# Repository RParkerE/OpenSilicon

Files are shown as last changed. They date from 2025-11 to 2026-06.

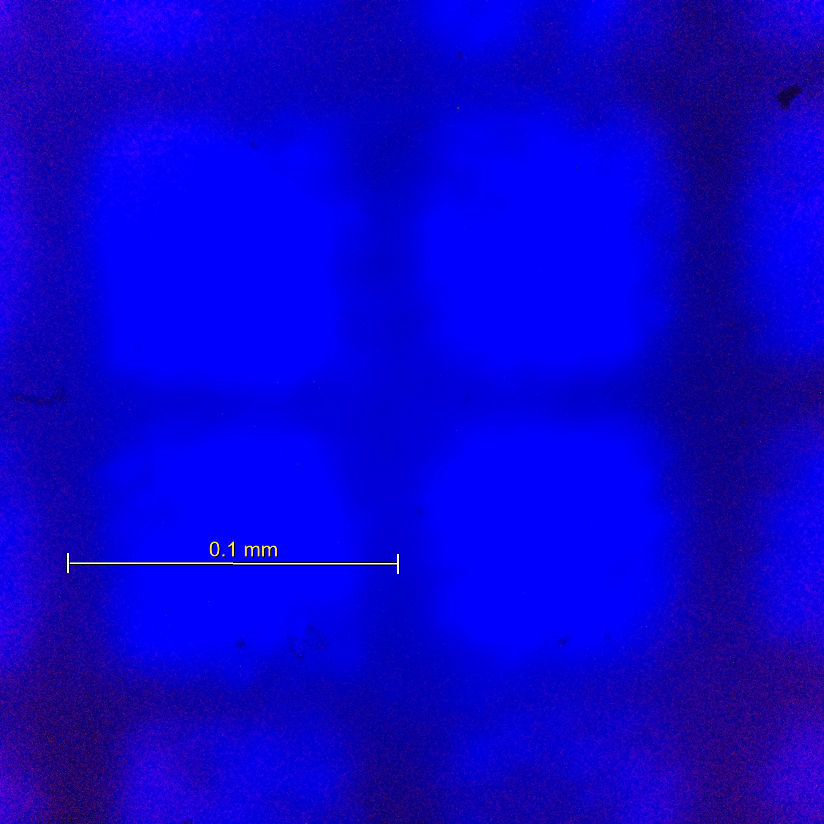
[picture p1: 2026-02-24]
Metrology/FPM/Examples/test_raw_annotated.png

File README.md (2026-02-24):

# OpenSilicon





Open-source semiconductor fabrication for the home lab. Build and operate IC fabrication equipment with detailed guides, CAD files, firmware, and process recipes.

## About

OpenSilicon brings semiconductor fabrication capabilities into the home lab. This project provides comprehensive documentation, designs, and software for building functional IC fabrication equipment for research, education, and experimentation.

We are currently developing the alpha stage of the fabrication pipeline, targeting sub micron feature resolution across the complete process flow: spin coating, direct write lithography, metrology, oxidation, and physical vapor deposition (PVD).

## Status

**Alpha Stage - Active Development**

This is an early-stage project. All equipment designs and processes are works in progress and subject to change. Current development is running two parallel tracks:

**Metrology (FPM / R-FPM)**
- Working prototype complete
- Fourier Ptychographic Microscopy (FPM) and Reflective FPM (R-FPM) under active characterization

**Direct Write Lithography (405nm)**
- Laser control code and firmware complete
- Actively working on motion circuitry and positioning firmware
- Investigating voice coil actuators from blu-ray drive for fine positioning
- Separate 3-axis alignment tool in development

**Other Systems**
- Spin coating system
    - Prototype full assembly complete
    - TODO: Look into web socket connectivity issues
    - TODO: Add a resist fill method
- Oxidation furnace fabrication pipeline
- PVD deposition system integration
- Process characterization and documentation

Join us to help shape the project during these formative stages.

## Getting Started

### Prerequisites

- Basic electronics and mechanical assembly experience
- Interest in semiconductor fabrication and experimental work
- Familiarity with working safely with high temperatures and electrical systems
- 3D printer access (optional, for custom components)

### Next Steps

1. Review the documentation to understand the current state of each component
2. Check open issues to see what's being worked on
3. Start contributing - documentation, testing, and feedback are valuable at this stage

## Equipment in Development

| Equipment | Status | Notes |
|---|---|---|
| Spin Coater | In Progress | Open issues remain |
| FPM / R-FPM Metrology | Working Prototype | Active characterization |
| Direct Write Lithography | In Progress | Laser firmware complete; positioning and alignment in development |
| 3-Axis Alignment Tool | In Progress | Companion to lithography system |
| Oxidation Furnace | In Progress | Initial build phase |
| PVD Deposition System | In Progress | Initial build phase |

## License

OpenSilicon is licensed under the **GNU General Public License v3**. See [LICENSE](LICENSE) for details.

This project integrates components licensed under GPLv3. When using or modifying this project, you must:

- Provide source code to users
- License derivative works under GPLv3
- Include a copy of the license
- State significant changes made

## Contributing

We actively welcome contributions. This project is in its early stages, and input from the community is essential.

### Getting Started with Contributing

1. Check [open issues](../../issues) and [discussions](../../discussions)
2. Reach out with ideas or questions before starting major work
3. Submit pull requests for feedback and discussion

### Ways to Contribute

- Share feedback on design decisions and approaches
- Document your work and help build the knowledge base
- Report issues, problems, observations, and learnings
- Propose design changes or optimizations
- Contribute firmware, software, and design improvements
- Help characterize equipment performance

## Community

- **GitHub Discussions**: [Ask questions and discuss ideas](../../discussions)
- **Issues**: [Report bugs and suggest features](../../issues)
- **Email**: [parker.ellwanger@gmail.com](mailto:parker.ellwanger@gmail.com)

## Roadmap

- [ ] Complete FPM/R-FPM metrology characterization
- [ ] Complete lithography positioning system (voice coil + 3-axis alignment)
- [ ] Complete alpha stage (sub micron) for all equipment
- [ ] Finalize process procedures and characterization data
- [ ] Publish comprehensive build guides
- [ ] Establish baseline performance metrics
- [ ] Improve lithography system resolution to work with the Open PDKs at 130nm process

## Performance & Limitations

OpenSilicon is targeting:

- **Feature resolution**: sub micron (alpha stage)
- **Use case**: Research, education, and experimentation
- **Scale**: Small-batch processing
- **Goal**: Accessible home lab fabrication, not production

## Safety

**This project involves significant hazards.** Home semiconductor fabrication includes:

- High temperature operation (up to 1000°C+)
- High voltage electrical systems
- UV radiation exposure
- Chemical hazards

Users are responsible for understanding and mitigating these risks. Always follow safety procedures and never operate equipment unsupervised.

## Building from Source

All designs are provided in open formats. No proprietary software is required:

- **CAD Files**: STEP and STL formats
- **Firmware**: Open-source microcontroller code
- **Software**: Python and standard development tools

## Acknowledgments

OpenSilicon builds on research and contributions from the open-source hardware community and makers exploring accessible semiconductor fabrication.

## Disclaimer

Use of OpenSilicon designs and instructions is at your own risk. The authors assume no liability for injuries, property damage, or other consequences from assembly, operation, or misuse of equipment built from these designs.

## Support

If you find OpenSilicon interesting, star this repository, share your interests and expertise, contribute to development, and help improve documentation.

**Have questions?** [Start a discussion](../../discussions) or [email us](mailto:parker.ellwanger@gmail.com).

**Found an issue?** [Report it](../../issues/new).

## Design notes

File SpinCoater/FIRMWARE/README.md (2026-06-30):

# OpenSilicon Spin Coater

Open-source firmware for a benchtop **spin coater** built around an ESP32. It
aspirates and dispenses photoresist onto a wafer, sets the dispense height with a
TMC2209-driven Z axis, and spins the wafer at a target RPM with a brushless
motor + ESC to spread the resist into a uniform film.

The machine is configured and operated from a built-in Wi-Fi web UI, with a
local TFT showing live status.

Wiring overview

## Hardware at a glance

| Subsystem | Part | Role |
| --- | --- | --- |
| Controller | ESP32 DevKit (`esp32dev`) | Runs everything |
| Spindle | AM32 ESC + brushless motor | Spins the wafer at target RPM |
| Dispense height (Z)  | TMC2209 + NEMA17 stepper | Raises/lowers the dispense head |
| Resist pump | 28BYJ-48 stepper + ULN2003 driver | Aspirates / dispenses resist |
| Display | ILI9341 320x240 SPI TFT | Local status screen |
| Home reference | Z limit switch | Z homing |

See [docs/HARDWARE.md](docs/HARDWARE.md) for the full bill of materials and the
software toolchain, [docs/WIRING.md](docs/WIRING.md) for the circuit and pin map,
and [docs/ESC_SETUP.md](docs/ESC_SETUP.md) for configuring the ESC.

## Quick start

1. Install [PlatformIO](https://platformio.org/) (the VS Code extension or the
   `pio` CLI).
2. Wire the hardware per [docs/WIRING.md](docs/WIRING.md) and configure the ESC
   per [docs/ESC_SETUP.md](docs/ESC_SETUP.md).
3. Flash the firmware and the web assets:

   ```bash
   pio run -t upload      # firmware
   pio run -t uploadfs    # web UI (data/ -> LittleFS)
   ```

4. Power on. The ESP32 starts a Wi-Fi access point:

   - **SSID:** `OpenSiliconSC`
   - **Password:** `coater123`
   - **URL:** `http://192.168.4.1`

5. Open the URL, build a recipe, **Load to Device**, then **Start**.

## How a recipe runs

Each recipe is an ordered list of steps. For every step the
`ProcessOrchestrator` sequences the hardware:

```
Prime (aspirate) -> lower Z to dispense height -> dispense resist
  -> raise Z to spin height -> ramp spindle to RPM -> hold -> ramp down -> next step
```

Per-step parameters (set in the web UI):

| Field | Meaning |
| --- | --- |
| Prime (mL) | Resist to aspirate before dispensing (0 = skip) |
| Dispense (mL) | Volume dispensed onto the wafer |
| Disp H (mm) | Z height while dispensing (head lowered) |
| Spin H (mm) | Z height while spinning (head retracted) |
| Speed (RPM) | Target spindle speed |
| Ramp (s) | Time to spin up to / down from speed |
| Hold (s) | Time held at speed |

## Architecture

```
WebSocket / TFT
      |
StateMachine  <—events—  ProcessOrchestrator
      |                        |
      |                   Controllers (Spin / Pump / ZAxis)
      |                        |
      +———————————————————> HAL (EscSpinMotor, TMC2209ZAxis, Pump28BYJ48, TFTDisplayHAL)
```

- **HAL** (`include/hal`, `src/hal`) — thin hardware drivers behind interfaces.
- **Controllers** (`include/controllers`, `src/controllers`) — wrap the HAL,
  service motion, and emit completion events.
- **ProcessOrchestrator** (`src/services/ProcessOrchestrator.cpp`) — the recipe
  state machine; the only place that knows the dispense/spin sequence.
- **StateMachine** — owns the machine state (Idle / Running / Paused / Fault).
- **Services** — `TelemetryService` builds a single snapshot; `DisplayService`
  renders it. Neither touches hardware directly.

## Calibration

Two constants in `include/common/configs.h` must be tuned to your mechanics:

- `Z_STEPS_PER_MM` — steps per mm of head travel.
- `PUMP_STEPS_PER_ML` — pump steps per mL (dispense a known volume and adjust).

## Safety

This drives a high-speed brushless motor and dispenses chemicals. Always run the
spindle inside an enclosure, keep the prop balanced, bench-test the ESC with the
motor **unloaded** first, and handle photoresist/solvents with appropriate PPE
and ventilation.

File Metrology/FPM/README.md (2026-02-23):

# R-FPM , Fourier Ptychography Microscope

A sub-500 nm resolution metrology instrument built for lithography feature
verification using Fourier Ptychographic Microscopy (FPM). Every acquisition
runs full FPM reconstruction to achieve synthetic-aperture resolution beyond
the conventional Abbe diffraction limit. The system supports two optical
geometries selected at acquisition time:

| Mode | LED position | Sample type | Phase output |
|---|---|---|---|
| **Reflection** | Above sample via beam splitter | Opaque / reflective (silicon, metal film) | Surface height: `h = φλ/(4π)` |
| **Transmission** | Below sample, shining up | Transparent (glass, quartz, photoresist) | Optical thickness: `h = φλ/(2π(n−1))` |

The reconstruction algorithm (Gerchberg-Saxton iterative phase retrieval)
is identical in both modes. Only the physical LED position and the
phase-to-height interpretation differ.

---

## Table of Contents

1. [Theory and Mathematics](#1-theory-and-mathematics)
2. [Operating Modes](#2-operating-modes)
3. [System Architecture](#3-system-architecture)
4. [Bill of Materials](#4-bill-of-materials)
5. [Hardware Assembly](#5-hardware-assembly)
6. [Software Setup](#6-software-setup)
7. [Configuration Reference](#7-configuration-reference)
8. [Code Module Reference](#8-code-module-reference)
9. [Acquisition Workflow](#9-acquisition-workflow)
10. [Image Quality Assessment](#10-image-quality-assessment)
11. [Reconstruction Algorithm](#11-reconstruction-algorithm)
12. [Calibration Procedure](#12-calibration-procedure)
13. [Target Resolution Budget](#13-target-resolution-budget)

---

## 1. Theory and Mathematics

### 1.1 Fourier Ptychography , Conceptual Foundation

Standard optical microscopy is bounded by the **Abbe diffraction limit**:

```
d = λ / (2 · NA)
```

where `d` is the minimum resolvable feature, `λ` is illumination wavelength,
and `NA` is the objective numerical aperture. For this system at λ = 395 nm
and NA = 0.25:

```
d_conventional = 395 nm / (2 × 0.25) = 790 nm
```

This is insufficient for sub-500 nm lithography verification. FPM overcomes
this limit by synthesizing a **larger effective aperture** from a sequence of
low-resolution images captured under angularly diverse illumination.

Each LED in the 5×5 array illuminates the sample from a different angle,
shifting the object's spatial frequency content into the passband of the
objective. The iterative reconstruction stitches these shifted spectral
patches together in Fourier space, recovering spatial frequencies the
objective cannot capture under on-axis illumination alone.

### 1.2 Illumination Wave Vector

For LED at grid position `(m, n)` where `m, n ∈ {-2, -1, 0, 1, 2}`, the
physical position on the array is:

```
x_led = m · d_pitch      (meters)
y_led = n · d_pitch
```

The illumination angle at the sample plane:

```
θ_x = arctan(x_led / h)
θ_y = arctan(y_led / h)
```

where `h` is the vertical distance from LED array to sample (led_height_mm).
The incident wave vector components:

```
k_x = k₀ · sin(θ_x)
k_y = k₀ · sin(θ_y)
k₀  = 2π / λ            (wave number)
```

The small-angle approximation `sin(θ) ≈ tan(θ)` is valid for `θ < 15°`.
For this system with `d_pitch = 8 mm` and `h = 50 mm`, the corner LED
angle is `arctan(2√2 × 8 / 50) ≈ 24°`, so the full sine is used.

### 1.3 Fourier Space Shift (Pixel Units)

Reconstruction is performed in discrete Fourier space. Each wave
vector is converted to a pixel shift within the upsampled spectrum:

```
Δk_x_pixels = k_x / δk_x
Δk_y_pixels = k_y / δk_y
```

where the Fourier sampling interval is:

```
δk_x = 2π / (W · p_eff)
δk_y = 2π / (H · p_eff)
```

`W`, `H` are the image width and height in pixels, and `p_eff` is the
effective pixel size at the sample plane:

```
p_eff = p_sensor / M
p_sensor = 1.12 μm    (IMX219 native pixel pitch)
M        = 10         (objective magnification)
p_eff    = 0.112 μm = 112 nm
```

### 1.4 Synthetic Numerical Aperture

The synthetic NA after FPM reconstruction is:

```
NA_synthetic = NA_obj + NA_illumination
NA_illumination = sin(θ_max)
θ_max = arctan(√2 · 2 · d_pitch / h)    (corner LED)
```

For this system:

```
θ_max = arctan(√2 × 2 × 0.008 / 0.050) = arctan(0.452) ≈ 24.3°
NA_illumination ≈ sin(24.3°) ≈ 0.412
NA_synthetic    ≈ 0.25 + 0.412 = 0.662
```

Theoretical synthetic resolution:

```
d_synthetic = λ / (2 · NA_synthetic)
            = 395 nm / (2 × 0.662)
            ≈ 298 nm
```

This is well within the sub-500 nm target.

> **Requirement for this to hold:** Adjacent LED spectra must overlap in
> Fourier space by at least 30%. Overlap fraction is:
>
> ```
> overlap = 1 - (|Δk| / (2 · k_obj_radius))
> k_obj_radius = k₀ · NA_obj
> ```
>
> If `|Δk| > 2 · k_obj_radius`, spectra do not overlap and the
> Gerchberg-Saxton update is operating blind (no spectral continuity
> constraint). The primary failure mode to check during calibration.

### 1.5 Gerchberg-Saxton Phase Retrieval

The reconstruction is based on the
Gerchberg-Saxton (GS) algorithm adapted for FPM by Zheng et al. (2013).

**State:** A complex-valued high-resolution object spectrum
`O(k_x, k_y)` of shape `(N·U, M·U)` where `U` is the upsample factor
(default 4×).

**Per-iteration update for each LED `i`:**

1. Extract the spectral patch centered at `(Δk_xi, Δk_yi)`:
   ```
   ψ_i(k) = O(k + Δk_i) · P(k)
   ```
   where `P(k)` is the binary pupil function (objective aperture).

2. Inverse FFT to spatial domain:
   ```
   φ_i(r) = ℱ⁻¹{ψ_i(k)}
   ```

3. **Amplitude constraint** , replace amplitude with square root of
   measured intensity, preserve phase:
   ```
   φ_i'(r) = √I_i(r) · exp(j · arg(φ_i(r)))
   ```

4. Forward FFT back to Fourier domain:
   ```
   ψ_i'(k) = ℱ{φ_i'(r)}
   ```

5. Update high-resolution spectrum:
   ```
   O'(k + Δk_i) = O(k + Δk_i) · (1 - P(k)) + ψ_i'(k) · P(k)
   ```

**Convergence metric** (relative change between iterations):

```
ε = ‖O_new - O_old‖_F / ‖O_old‖_F
```

Iteration stops when `ε < convergence_threshold` (default 1×10⁻⁴) or
`max_iterations` is reached (default 15).

**Final reconstruction:**

```
object(r) = ℱ⁻¹{O(k)}
amplitude  = |object(r)|
phase      = arg(object(r))
```

### 1.6 Pupil Function

The objective lens is modeled as a binary circular aperture:

```
P(k) = 1   if √(k_x² + k_y²) ≤ NA_obj / λ
P(k) = 0   otherwise
```

The coherent transfer function (CTF) of a diffraction-limited
objective in the paraxial approximation (Born & Wolf, §10.6).

### 1.7 Phase-to-Height Conversion (Mode-Dependent)

The phase output of the GS reconstruction, `φ(r) ∈ [−π, π]`, encodes a
physical quantity that depends on the optical geometry.

**Reflection mode** (light travels to the surface and back , double pass):

```
φ = (4π / λ) · h
→  h = φλ / (4π)
```

`h` is the surface height in nm. Sensitivity is `λ/2 = 197 nm` per `2π`
of phase, so one full phase wrap corresponds to ~197 nm of topography.

**Transmission mode** (light passes through the sample once , single pass):

```
φ = (2π / λ) · (n − 1) · t
→  t = φλ / (2π(n − 1))
```

`t` is the physical thickness of the sample in nm. `n` is the sample
refractive index (configured via `sample_refractive_index` in `config.py`).
Sensitivity is `λ / (n − 1)` per `2π` of phase , for glass (`n ≈ 1.5`),
one full phase wrap corresponds to ~790 nm of thickness.

**Refractive index reference values:**

| Material | n at 395 nm |
|---|---|
| Borosilicate glass | 1.47 |
| Fused silica (quartz) | 1.47 |
| Positive photoresist (AZ) | 1.64 |
| PMMA | 1.50 |
| Water | 1.34 |
| Air (reference) | 1.00 |

The `visualize.py` dashboard applies the correct formula automatically by
reading the mode from `status.json`. The refractive index can be overridden
interactively in the 3D surface tab without re-running reconstruction.

### 1.8 Abbe Resolution Limit Reference Table

| Configuration | NA | Resolution |
|---|---|---|
| Conventional (this objective) | 0.25 | 790 nm |
| FPM synthetic (estimated) | 0.662 | 298 nm |
| Target | , | < 500 nm |
| IMX219 Nyquist at sample plane | , | 224 nm |

The sensor Nyquist limit at the sample plane (`2 × p_eff = 224 nm`) is the
hard floor below which no reconstruction can recover detail regardless of NA.
The synthetic resolution (298 nm) is above this floor, so the sensor is not
the bottleneck.

---

## 2. Operating Modes

Both modes run full FPM reconstruction. The mode controls only where the
LED array is physically mounted and how the phase output is interpreted.

### 2.1 Reflection Mode

```
         [ 5×5 UV LED array ]
                  │  angled illumination
                  ▼
         [ 50/50 Beam Splitter ]  ← mounted at 45°
                  │  reflected arm
                  ▼
            [ Sample plane ]       ← opaque / reflective
                  │  backscattered light
                  ▼
          [ 10× Objective ]
                  │
                  ▼
           [ IMX219 Camera ]
```

**Use for:** Silicon wafers, metal thin films, hard disk platters, any
surface that scatters or reflects light without being transmissive.

**Phase output:** Surface topography. Each pixel's phase value encodes how
much higher or lower that point is relative to the mean surface plane.

**Beam splitter requirement:** The 46×57×0.5 mm 50/50 plate is in the
optical path. It introduces a 50% transmission loss on both the
illumination and collection passes (25% total efficiency). The
primary reason exposure times are long in reflection mode.

### 2.2 Transmission Mode

```
            [ Sample plane ]       ← transparent (glass, resist, quartz)
                  │  transmitted light
                  ▼
          [ 10× Objective ]
                  │
                  ▼
           [ IMX219 Camera ]

         [ 5×5 UV LED array ]     ← mounted BELOW sample, shining up
```

**Use for:** Thin film samples on transparent substrates, patterned
photoresist on glass, biological specimens on glass slides, any sample
that transmits UV light.

**Phase output:** Optical path length through the sample. Combined with
the refractive index, this gives physical thickness at each pixel.

**Beam splitter requirement:** Not needed. Remove it from the optical path
or fold it out of the beam. Transmission efficiency is significantly
higher , exposures can be 5–10× shorter than reflection mode for the
same SNR.

**LED array repositioning:** The LED jig must be moved from above the
beam splitter to below the sample stage. The `led_height_mm` parameter
in `config.py` must be updated to the new measured distance from the
LED array plane to the sample underside.

### 2.3 What Does Not Change Between Modes

- The GS reconstruction algorithm (`reconstruction.py`) , identical.
- The k-space coordinate calculation (`utils.py`) , identical. Illumination
  angle geometry is the same whether the LED is above or below.
- The `val.py` quality assessment , identical. Alignment, exposure, and
  focus checks apply equally in both modes.
- The session file format , identical. `led_NN.png`, `status.json`, and
  the TIFF outputs have the same structure.

### 2.4 Selecting a Mode

```bash
# Reflection mode (default) , opaque sample, beam splitter in path
python client.py --mode reflection

# Transmission mode , transparent sample, LED below stage
python client.py --mode transmission

# Set default in .env to avoid passing --mode every time
echo "FPM_MODE=transmission" >> .env
```

The mode is stored in the session manifest at capture time and in
`status.json` at reconstruction time. The `visualize.py` dashboard reads
it automatically , no manual configuration is needed when browsing results.

---

## 3. System Architecture

```
┌─────────────────────────────────────────────────────────────┐
│                    Raspberry Pi 4B                           │
│                                                             │
│   client.py ─── picamera2 ─── IMX219 sensor                │
│       │                            │                        │
│       │ pyserial (115200 baud)     │ CSI-2 lane             │
│       │                            ▼                        │
│       │                       led_XX.png                    │
│       │                            │                        │
│       │                      HTTP POST /upload              │
│       │                            │                        │
└───────┼────────────────────────────┼────────────────────────┘
        │                            │
        ▼                            ▼
┌──────────────┐           ┌─────────────────────────────────┐
│   ESP32      │           │     Server (Docker / bare)      │
│              │           │                                 │
│ SPI → 4×    │           │   server.py (FastAPI)           │
│ 74HC595     │           │   reconstruction.py (GS)        │
│ shift regs  │           │   utils.py (k-space coords)     │
│             │           │   visualize.py (Streamlit)      │
│ 25 UV LEDs  │           │   val.py (QA tool, local)       │
│ 5×5 grid    │           │                                 │
└──────────────┘           │   :8000 REST API               │
                           │   :8501 Dashboard              │
                           └─────────────────────────────────┘
```

**Optical path , Reflection mode** (LED above sample, beam splitter required):

```
  UV LED array (395 nm)
        │  angled illumination
        ▼
  ┌─────────────┐
  │ Beam Splitter│  46×57×0.5mm, 50/50 ratio
  └─────┬───────┘
        │ reflected down onto sample
        ▼
    Sample plane  (opaque/reflective)
        │ backscattered light up through splitter
        ▼
  10× Objective (NA 0.25)
        │
        ▼
  IMX219 Camera
```

**Optical path , Transmission mode** (LED below sample, no beam splitter):

```
  IMX219 Camera
        │
        ▼
  10× Objective (NA 0.25)
        │
        ▼
    Sample plane  (transparent)
        │ transmitted light
        ▼
  UV LED array (395 nm)  ← mounted below stage
```

### 3.1 Data Flow Per Acquisition

```
python client.py --mode <reflection|transmission>
    → ESP32 serial "L{n} E{ms}"
    → LED n fires for exposure_ms
    → Pi camera captures frame
    → saved as led_NN.png
    → repeated for all 25 LEDs
    → mode written to session manifest JSON
    → 25 images uploaded to server
    → POST /process/{session_id}?mode=<reflection|transmission>
    → mode stored in status.json
    → reconstruction runs (identical algorithm in both modes)
    → amplitude + phase TIFFs written to session dir
    → Streamlit dashboard reads mode from status.json
    → applies correct phase-to-height formula for the mode
```

---

## 4. Bill of Materials

| # | Component | Part / Spec | Role |
|---|---|---|---|
| 1 | **Objective Lens** | OMAX 10× Achromatic, NA 0.25, RMS thread, 160mm tube length | Primary imaging element. Sets base resolution and field of view. |
| 2 | **Microcontroller** | ESP32 (38-pin DevKit, dual-core 240 MHz, Wi-Fi/BT) | LED array sequencing via SPI + 4× shift registers. Serial command interface to Pi. |
| 3 | **UV LED Array** | EDGELEC 3mm, 395–400 nm, flat lens, DC 3V, ~20 mA/LED. 25 pcs arranged in 5×5 grid on 8 mm pitch PCB/jig | Angularly diverse illumination source. UV chosen for shortest λ → best diffraction limit. |
| 4 | **Camera** | Arducam IMX219 8MP, RPi NoIR (no IR filter), CSI-2 | Scientific imaging sensor. 3280×2464 native, 1.12 μm pixel pitch. NoIR variant avoids IR-cut filter UV absorption. |
| 5 | **Beam Splitter** | Optical glass, 46×57×0.5mm, 50/50 split ratio | Directs LED illumination onto sample in reflection geometry while passing return light to camera. |
| 6 | **Shift Registers** | SN74HC595N, 8-bit, DIP-16, 3-state output. 4 pcs in daisy-chain (32 outputs, 25 used) | Expands ESP32 SPI to 25 individual LED control lines. |
| 7 | **SBC** | Raspberry Pi 4B (4GB RAM recommended) | Acquisition host: runs client.py, picamera2, serial comms. |

### 4.1 Supplementary Materials

| Item | Specification | Notes |
|---|---|---|
| LED current-limiting resistors | 100 Ω for 6–12V supply; included in EDGELEC kit | Verify drop across LED (~3.2V forward) at 20 mA |
| Sample slide | Quartz preferred; plastic usable with <8s exposure | See §12 fluorescence note |
| Tube adapter | RMS-to-C-mount or RMS-to-M12 for IMX219 board | Mechanical coupling between objective and sensor |
| Optical rail / cage system | 30mm or 60mm cage, Thorlabs or equivalent | Rigidity critical , any vibration aliases phase error |
| LED jig/PCB | 5×5 matrix, 8mm pitch, 3mm LED holes | Custom or perf-board construction |
| DC power supply | 5V/3A for Pi; 9V/1A for LED array; 3.3V/5V for ESP32 | Separate supplies reduce ground noise |

---

## 5. Hardware Assembly

### 5.1 LED Array Wiring (ESP32 → 74HC595 Chain)

The four shift registers are daisy-chained: `Q7'` (serial out) of register N
connects to `DS` (serial in) of register N+1.

```
ESP32 GPIO 23 (MOSI) ──► DS   [SR1] Q7' ──► DS   [SR2] Q7' ──► DS   [SR3] Q7' ──► DS   [SR4]
ESP32 GPIO 18 (SCK)  ──► SHCP (all four, parallel)
ESP32 GPIO 5  (LATCH)──► STCP (all four, parallel)
GND ─────────────────────────────────────────────────────────────────────────────────── GND
```

`SPI.transfer32()` clocks 32 bits MSB-first. Bit 0 activates the output on
the last register in the chain (SR4 pin Q0). Bit 24 activates SR1 pin Q0.
Bits 25–31 are unused.

**LED index mapping** (1-based, matches `led_NN.png` filenames):

```
LED grid (physical, viewed from above):
Row 0 (top):   LED 1  LED 2  LED 3  LED 4  LED 5
Row 1:         LED 6  LED 7  LED 8  LED 9  LED 10
Row 2 (center):LED 11 LED 12 LED 13 LED 14 LED 15
Row 3:         LED 16 LED 17 LED 18 LED 19 LED 20
Row 4 (bottom):LED 21 LED 22 LED 23 LED 24 LED 25

Shift register bit assignment:
LED index n → bit (n-1) in the 32-bit SPI word
```

> **Critical:** Verify your physical wiring matches this mapping before
> the first acquisition. Fire LEDs 1, 5, 21, 25 (corners) and 13 (center)
> individually and confirm the centroid positions are as expected.
> See §11 Calibration Procedure.

### 5.2 Serial Command Protocol (ESP32)

Communication is ASCII over UART at 115200 baud, newline-terminated.

| Command | Response | Description |
|---|---|---|
| `L{n} E{ms}\n` | `PULSING_LED_INDEX:{n}` then `PULSE_COMPLETE` | Fire LED n (1-25) for ms milliseconds |
| `STATUS\n` | `LED_ACTIVE:{n}` or `LED_ACTIVE:0` | Query active LED |
| `RESET\n` | `SYSTEM_RESET` | Clear all registers, safe state |

Maximum pulse duration: 180,000 ms (3 minutes). The ESP32 auto-shutoff
timer fires `PULSE_COMPLETE` and extinguishes the LED when elapsed.

### 5.3 Optical Alignment

1. Mount beam splitter at 45° to both the illumination axis and the imaging axis.
2. Center the objective below the beam splitter exit port.
3. Place sample on the objective focal plane (~17.4 mm WD for this objective).
4. Align the LED array so LED 13 (center) illumination hotspot falls at the
   image center `(1024, 1024)` for a 2048×2048 capture.
5. The LED array plane should be parallel to the sample plane. Use a spirit
   level on the LED jig.
6. Target `led_height_mm = 50` ± 2 mm. Measure with calipers and update `config.py`.

---

## 6. Software Setup

### 6.1 Prerequisites

- Python 3.10+
- [`uv`](https://github.com/astral-sh/uv) package manager
- Docker + Docker Compose (for server deployment)
- Arduino IDE or `arduino-cli` (for ESP32 firmware)

### 6.2 Python Environment (Client + QA Tools)

```bash
# Clone the repository
git clone https://github.com/<your-org>/r-fpm.git
cd r-fpm

# Create virtual environment and install dependencies
uv venv
uv pip install -r requirements.txt

# Activate environment
source .venv/bin/activate        # Linux / macOS
.venv\Scripts\activate           # Windows
```

### 6.3 Server Deployment (Docker)

```bash
# Build and start the API server and Streamlit dashboard
docker compose up -d

# Verify health
curl http://localhost:8000/health

# View logs
docker compose logs -f api
```

The server exposes:
- `http://localhost:8000` , FastAPI REST API
- `http://localhost:8501` , Streamlit visualization dashboard

### 6.4 Environment Variables

Override any config value with the `FPM_` prefix:

```bash
# Example: switch to quartz target profile
export FPM_ACQUISITION__BF_EXPOSURE_US=60000000
export FPM_ACQUISITION__ANALOG_GAIN=8.0
export FPM_OPTICAL__LED_HEIGHT_MM=52.5   # measured value
```

### 6.5 ESP32 Firmware

Open `firmware/led_controller.ino` in Arduino IDE. Set board to
**ESP32 Dev Module**. Flash via USB. Verify with serial monitor at 115200 baud ,
`SHIFT_REGISTER_SYSTEM_READY` should print on boot.

---

## 7. Configuration Reference

All system parameters are defined in `config.py` using Pydantic settings.
Values can be overridden via environment variables or `.env` file.

### 7.1 SystemConfig (top-level)

| Parameter | Default | Description |
|---|---|---|
| `mode` | `"reflection"` | Operating geometry. `"reflection"` = LED above sample via beam splitter; `"transmission"` = LED below sample. Override with `FPM_MODE=transmission`. |

### 7.2 OpticalConfig

| Parameter | Default | Unit | Description |
|---|---|---|---|
| `wavelength_nm` | 395.0 | nm | LED center wavelength |
| `na_objective` | 0.25 | , | Objective numerical aperture |
| `pixel_size_um` | 1.12 | μm | IMX219 native pixel pitch |
| `magnification` | 10.0 | × | Objective magnification |
| `led_pitch_mm` | 8.0 | mm | LED-to-LED spacing in array |
| `led_height_mm` | 50.0 | mm | Distance from LED array to sample plane. **Remeasure and update when switching to transmission mode** , the LED array moves from above the beam splitter to below the sample stage. |
| `sample_refractive_index` | 1.5 | , | Sample refractive index for transmission mode thickness conversion. Has no effect in reflection mode. Typical values: glass/quartz 1.47, photoresist 1.64, water 1.34. |

**Derived properties** (read-only, computed at runtime):

| Property | Formula | Typical value |
|---|---|---|
| `pixel_size_m` | `pixel_size_um × 1e-6 / magnification` | 112 nm |
| `theoretical_resolution_nm` | `wavelength_nm / (2 × na_objective)` | 790 nm |
| `synthetic_na_estimate` | `na_obj + sin(arctan(√2 × 2 × pitch / height))` | 0.662 |
| `synthetic_resolution_nm` | `wavelength_nm / (2 × synthetic_na_estimate)` | ~298 nm |

### 7.3 AcquisitionConfig

| Parameter | Default | Description |
|---|---|---|
| `serial_port` | `/dev/ttyUSB0` | ESP32 serial device |
| `camera_width` | 2048 | Capture width (pixels) |
| `camera_height` | 2048 | Capture height (pixels) |
| `bf_exposure_us` | 9,600,000 | Bright-field exposure (9.6 s) |
| `df_exposure_us` | 9,600,000 | Dark-field exposure (9.6 s) |
| `analog_gain` | 16.0 | Camera gain (1.0–16.0) |
| `capture_timeout_s` | 60 | Max wait per frame |

### 7.4 Exposure Profiles

| Profile | Target | bf_exposure_us | df_exposure_us | analog_gain | Signal |
|---|---|---|---|---|---|
| Plastic target (current) | Below fluorescence threshold | 7,000,000 | 7,000,000 | 16.0 | 5–10% FS , marginal |
| **Quartz target (recommended)** | Maximum SNR | 60,000,000 | 120,000,000 | 8.0 | 30–60% FS , good |
| Blue LED 470 nm (best) | Fast + no fluorescence | 1,000,000 | 3,000,000 | 4.0 | 40–80% FS , excellent |

> **Fluorescence warning:** The plastic calibration slide exhibits
> UV-induced fluorescence (visible as a red/pink channel bleed in the
> camera raw) at exposures exceeding ~8–10 seconds. This contaminates
> the measured intensity with incoherent emission rather than coherent
> scattered signal, violating the FPM measurement model. Use a quartz
> slide for exposures above 8 s.

### 7.5 ReconstructionConfig

| Parameter | Default | Range | Description |
|---|---|---|---|
| `upsample_factor` | 4 | 2–8 | High-res grid size = input × upsample_factor |
| `max_iterations` | 15 | 1–100 | GS iteration limit |
| `convergence_threshold` | 1×10⁻⁴ | >0 | Early stopping relative change |
| `regularization_weight` | 0.01 | 0–1 | Tikhonov noise suppression |

---

## 8. Code Module Reference

### 8.1 `config.py` , System Configuration

Centralized Pydantic settings model. All physical constants live here.

**`OperatingMode`** is a `Literal["transmission", "reflection"]` type alias
exported at module level. All other modules import this type to ensure
consistent validation:

```python
from config import config, OperatingMode
```

**`SystemConfig.mode`** sets the system-wide default geometry. Override
at the environment level without touching code:

```bash
FPM_MODE=transmission python client.py
# or persistently:
echo "FPM_MODE=transmission" >> .env
```

**`OpticalConfig.sample_refractive_index`** (default 1.5) is consumed
only by `visualize.py` in transmission mode when converting phase to
physical thickness. It has no effect on the reconstruction algorithm.

```python
from config import config

print(config.mode)                              # 'reflection'
print(config.optical.synthetic_resolution_nm)  # ~298 nm
print(config.optical.sample_refractive_index)  # 1.5
config.print_summary()                         # prints mode-aware summary
```

### 8.2 `utils.py` , Mathematical Utilities

**`get_k_coordinates(led_pitch_m, led_height_m, wavelength_m, na_obj, pixel_size_m, img_shape)`**

Computes the Fourier-space pixel shifts for all 25 LED positions.
Returns `(kx_shifts, ky_shifts)` as flat arrays of length 25.
These are the `Δk` values used in the GS update step.

**`generate_pupil(img_shape, na_obj, wavelength_m, pixel_size_m)`**

Returns a binary complex64 array representing the objective aperture
in Fourier space. Pixel value 1.0 inside NA cutoff, 0.0 outside.

**`calculate_theoretical_resolution(wavelength_m, na_effective)`**

Returns Abbe limit `λ / (2 × NA)` in meters.

**`estimate_synthetic_na(na_obj, led_pitch_m, led_height_m, wavelength_m)`**

Returns estimated synthetic NA based on LED geometry. Includes overlap
check: if adjacent spectra do not overlap, logs a warning.

### 8.3 `reconstruction.py` , FPM Reconstruction Engine

```python
from config import config
from reconstruction import FPMReconstructor

reconstructor = FPMReconstructor(config)
amplitude, phase, metadata = reconstructor.reconstruct(images, kx_shifts, ky_shifts)
```

**`FPMReconstructor.reconstruct(images, kx_shifts, ky_shifts)`**

- `images`: List of 25 float32 grayscale arrays
- `kx_shifts`, `ky_shifts`: Arrays from `get_k_coordinates()`
- Returns: amplitude array, phase array (radians), metadata dict

The metadata dict contains convergence history, processing time, and
the final relative change value. Useful for diagnosing reconstruction
quality without inspecting the output image.

### 8.4 `server.py` , FastAPI REST Server

| Endpoint | Method | Description |
|---|---|---|
| `/health` | GET | System health, default mode, and optical parameters |
| `/sessions` | GET | List all acquisition sessions |
| `/sessions/{id}/status` | GET | Reconstruction progress and mode |
| `/upload/{id}` | POST | Upload image stack (multipart) |
| `/process/{id}?mode=reflection` | POST | Trigger reconstruction with specified mode |

**`POST /process/{session_id}?mode=<mode>`** accepts `mode` as a query
parameter. The mode defaults to `config.mode` if omitted. It is stored in
`status.json` immediately (even before reconstruction completes) so the
visualizer can display the correct formula while processing is in progress.

**`GET /sessions/{id}/status`** response now includes a `"mode"` field:

```json
{
  "session_id": "fpm_1771347801",
  "status": "complete",
  "mode": "transmission",
  "frames_uploaded": 25,
  "reconstruction_complete": true
}
```

### 8.5 `client.py` , Raspberry Pi Acquisition Client

Runs on the Raspberry Pi. Sequences through all 25 LEDs, captures one
image per LED, and uploads the stack to the server.

**`--mode` flag** is the primary user-facing control for selecting the
optical geometry. It defaults to `config.mode` (set in `.env`):

```bash
python client.py --mode reflection   # LED above, beam splitter in path
python client.py --mode transmission # LED below, beam splitter removed
```

The mode is propagated through the full pipeline:
- Written into `{session_id}_manifest.json` at capture time (per-frame)
- Sent as `?mode=` query parameter to `POST /process/{session_id}`
- The server stores it in `status.json` for the visualizer to read

**`FPMConductor`** now takes `mode: OperatingMode` as a constructor
argument. The BF/DF LED split logic is identical in both modes , inner
3×3 LEDs always use `bf_exposure_us`, outer 16 use `df_exposure_us`.

### 8.6 `visualize.py` , Streamlit Dashboard

Runs at `:8501`. Reads the operating mode from `status.json` (written by
server) or the session manifest (written by client) and applies the
correct phase-to-height formula automatically.

**`load_session_mode(session_path)`** reads mode with a three-level fallback:
1. `status.json` → `"mode"` field (primary , written at reconstruction time)
2. `{session_id}_manifest.json` → `"mode"` field (written at capture time)
3. `config.mode` (fallback for sessions captured before mode tracking)

**`phase_to_height(phase_map, wavelength_nm, mode, refractive_index)`**
applies the correct conversion formula:

```python
# Reflection , double-pass surface height
height_nm = (phase_rad * wavelength_nm) / (4 * pi)

# Transmission , single-pass optical thickness
height_nm = (phase_rad * wavelength_nm) / (2 * pi * (n - 1))
```

In transmission mode the dashboard exposes a live `n` override slider in
the 3D surface tab, allowing immediate rescaling of the height axis for
different sample materials without re-running reconstruction.

**Mode badge** is displayed in both the sidebar and the main area so the
geometry is unambiguous when switching between sessions of different modes.

Provides:
- Session browser (sorted by modification time)
- 16-bit amplitude and phase image display
- Interactive 3D surface plot (Plotly) with quality slider
- RMS roughness, mean height, and peak-to-valley metrics

### 8.7 `val.py` , Image Quality Assessment Tool

Standalone diagnostic tool. Runs locally on the acquisition machine or
server. Evaluates each of the 25 LED images across three independent axes:

| Axis | Method | Metric | PASS threshold |
|---|---|---|---|
| **Alignment** | Intensity-weighted centroid of top-5% pixels | Distance from image center (px) | < 100 px |
| **Exposure** | Mean intensity + clipping fraction | % of full scale | 8–80% |
| **Focus** | Laplacian variance of central 50% ROI | Lap. var (unitless) | > 15.0 |

```bash
# Run quality assessment on a session
python val.py data/fpm_1771347801

# Save PNG report to custom path
python val.py fpm_1771347801 --output ./reports/session_qa.png
```

**Output files per session:**
- `alignment_analysis.png` , 3×2 quality dashboard
- `alignment_results.json` , Full per-LED metrics + thresholds

#### Focus Threshold Calibration

The `FOCUS_PASS = 15.0` threshold is a starting point. Calibrate it
for your specific sample and objective:

1. Capture a single image with the system in known-good focus.
2. Run `val.py` and note the `laplacian_variance` for that LED.
3. Set `FOCUS_PASS` to ~80% of that value in `val.py`.

For a blank slide (no sample), the Laplacian variance will be near zero
regardless of focus , this is expected. The focus metric only works when
the sample has spatial features at or near the sensor resolution limit.

---

## 9. Acquisition Workflow

Every acquisition runs full FPM reconstruction. The only choice is the
optical geometry , reflection or transmission , which determines where
the LED array sits and what the phase output means.

### 9.1 Reflection Mode Acquisition

LED array above sample via beam splitter. Use for opaque/reflective samples.

```bash
# 1. Ensure beam splitter is in the optical path.
#    LED array should be above the beam splitter at led_height_mm from sample.

# 2. Start server (if not already running)
docker compose up -d

# 3. On Raspberry Pi: run full 25-LED acquisition
python client.py --mode reflection --session fpm_$(date +%s)

# 4. Monitor reconstruction status
curl http://<server_ip>:8000/sessions/<session_id>/status

# 5. View results in dashboard (mode badge shown automatically)
open http://<server_ip>:8501
```

### 9.2 Transmission Mode Acquisition

LED array below sample, shining up through specimen. Use for transparent
samples. Before running:

1. **Remove or fold the beam splitter** out of the optical path between
   the objective and camera.
2. **Reposition the LED array** below the sample stage, shining upward.
3. **Measure the new `led_height_mm`** (LED array plane to sample underside)
   with calipers and update `config.py` or set `FPM_OPTICAL__LED_HEIGHT_MM`.

```bash
# Set new height if different from 50 mm
export FPM_OPTICAL__LED_HEIGHT_MM=42.5

# Run acquisition
python client.py --mode transmission --session fpm_$(date +%s)

# View results , dashboard applies transmission formula automatically
open http://<server_ip>:8501
```

### 9.3 Setting a Default Mode

To avoid passing `--mode` on every run, set it in `.env`:

```bash
echo "FPM_MODE=transmission" >> .env
# Now client.py, server.py, and visualize.py all default to transmission
```

### 9.4 LED Firing Order

LEDs fire in index order 1→25 (row-major, top-left to bottom-right).
The angular diversity and k-space shift mapping are identical in both
reflection and transmission modes.

BF LEDs (inner 3×3, indices 7, 8, 9, 12, 13, 14, 17, 18, 19): use
`bf_exposure_us`. DF LEDs (outer 16): use `df_exposure_us`.

---

## 10. Image Quality Assessment

Before triggering reconstruction, run `val.py` to verify the stack is
usable. The tool will flag any LED whose image fails on alignment, exposure,
or focus, and will print a per-LED table and an overall readiness verdict.

### 10.1 Interpreting the Table

```
LED   OVERALL   ALIGN   DIST    EXPOSE   MEAN%   CLIP%   FOCUS   LAP_VAR
1     PASS      PASS    45.2px  PASS     31.4%   0.00%   PASS     24.55
2     WARN      WARN    187.0px PASS     28.1%   0.00%   PASS     19.22
  -> ALIGN WARN: centroid 187px from center (PASS < 100px).
3     FAIL      PASS    62.0px  FAIL     3.1%    0.00%   PASS     21.33
  -> EXPOSURE FAIL: mean 3.1% , severely underexposed. Increase exposure.
```

### 10.2 Status Color Key

| Status | Meaning |
|---|---|
| **PASS** | Axis is within specification |
| **WARN** | Axis is marginal , reconstruction may succeed but quality is reduced |
| **FAIL** | Axis is out of specification , reconstruction likely to fail or produce artifacts |

### 9.3 Acquisition Readiness Verdict

| Verdict | Condition |
|---|---|
| `READY` | Zero FAILs, ≤5 WARNs |
| `MARGINAL` | 1–3 FAILs , address before acquiring |
| `NOT READY` | >3 FAILs , do not reconstruct |

---

## 11. Reconstruction Algorithm

### 11.1 High-Resolution Grid Initialization

The high-resolution spectrum is initialized using the center LED (index 12,
0-based) image. This provides the initial estimate of the object spectrum in
the passband of the objective. All other spectral regions start at zero.

```
high_res_shape = (2048 × upsample_factor, 2048 × upsample_factor)
               = (8192, 8192) at 4× upsample
```

### 11.2 Iteration Sequence

```
for iteration in range(max_iterations):
    for each LED (25 total):
        extract patch → apply pupil → iFFT → replace amplitude → FFT → update spectrum
    compute ε (relative change)
    if ε < convergence_threshold: break
```

Each full pass through all 25 LEDs constitutes one iteration. Typical
convergence at 15 iterations with 9.6 s exposures (marginal SNR).
With quartz target at 60 s exposure, convergence is typical at 5–8 iterations.

### 11.3 Output Files

| File | Format | Content |
|---|---|---|
| `reconstruction_amplitude.tiff` | 16-bit grayscale TIFF | Normalized amplitude (0–65535) |
| `reconstruction_phase.tiff` | 16-bit grayscale TIFF | Phase mapped from \[-π, π\] → \[0, 65535\] |
| `status.json` | JSON | Session status, operating mode, frame count, convergence metrics |

**Phase-to-height conversion** in `visualize.py` , formula selected by mode:

```python
phase_radians = (phase_uint16 / 65535.0) * (2π) - π

# Reflection mode (double-pass surface topography)
height_nm = (phase_radians × wavelength_nm) / (4π)

# Transmission mode (single-pass optical thickness)
height_nm = (phase_radians × wavelength_nm) / (2π × (n - 1))
```

The mode is read from `status.json` automatically. No manual formula
selection is required when viewing results in the dashboard.

---

## 12. Calibration Procedure

### 12.1 LED Mapping Verification

Fire each LED individually via the ESP32 serial console and measure
the centroid shift. Compare against geometric prediction:

```bash
# On any machine with the session data
python val.py data/<session_id>
```

Expected centroid positions (approximate, at 50mm height, 8mm pitch):

| LED | Grid pos | Expected centroid (approx) |
|-----|---|---|
| 13 (center) | (0, 0) | ~(1024, 1024) |
| 1 (TL corner) | (-2, -2) | ~(840, 840) |
| 5 (TR corner) | (+2, -2) | ~(1208, 840) |
| 21 (BL corner) | (-2, +2) | ~(840, 1208) |
| 25 (BR corner) | (+2, +2) | ~(1208, 1208) |

If centroids do not match, check:
1. `led_height_mm` , measure physically and update `config.py`
2. `led_pitch_mm` , measure center-to-center with calipers
3. Shift register wiring , confirm LED index to physical position mapping

### 12.2 Focus Calibration

1. Place a calibration target (USAF 1951 chart or lithography sample) on the stage.
2. Manually adjust focus by translating the objective or stage in Z.
3. Run `val.py` after each Z adjustment.
4. The `LAP_VAR` column increases monotonically as you approach focus.
5. Lock the focus at maximum `LAP_VAR` for the center LED (LED 13).
6. Record that value as your `FOCUS_PASS` baseline in `val.py`.

### 12.3 Exposure Calibration

Target 20–60% of full scale (51–153 DN out of 255) in the mean intensity
column of `val.py`. Adjust `bf_exposure_us` and `df_exposure_us` in
`config.py` until bright-field and dark-field LEDs both land in this range.

For the current plastic target with UV LEDs:
- Bright-field (center LEDs): target ~50–100 DN mean
- Dark-field (outer LEDs): target ~30–80 DN mean (less efficient coupling)
- **Hard limit at 7,000,000 μs (7 s) to avoid fluorescence**

For quartz target: no fluorescence limit applies. Target 80–150 DN mean
at 60–120 s exposure.

---

## 13. Target Resolution Budget

| Budget item | Value | Notes |
|---|---|---|
| Illumination wavelength | 395 nm | UV LED center |
| Objective NA | 0.25 | OMAX 10× achromat |
| Conventional resolution | 790 nm | Abbe limit at objective NA |
| LED illumination NA | 0.412 | Corner LED at 50mm height |
| Synthetic NA (estimated) | 0.662 | Sum: obj + illumination |
| Synthetic resolution (estimated) | **298 nm** | Abbe at synthetic NA |
| Sensor Nyquist at sample | 224 nm | 2 × 112 nm effective pixel |
| **Target** | **< 500 nm** | Lithography feature verification |
| **Margin** | +40% | 298 nm vs 500 nm target |

The 40% margin accounts for:
- Spectral overlap imperfection (typically reduces effective synthetic NA by 10–20%)
- Phase noise from low-SNR dark-field images
- Optical aberrations not modeled in the paraxial pupil function
- Residual alignment error between measured and predicted k-shifts

---

## References

- Zheng, G., Horstmeyer, R., & Yang, C. (2013). Wide-field, high-resolution Fourier
  ptychographic microscopy. *Nature Photonics*, 7(9), 739–745.
  https://doi.org/10.1038/nphoton.2013.187

- Born, M., & Wolf, E. (2019). *Principles of Optics* (7th ed.). Cambridge University Press.
  §10.6 (Coherent imaging), §8.6 (Pupil function).

- Ou, X., Horstmeyer, R., Yang, C., & Zheng, G. (2013). Quantitative phase imaging
  via Fourier ptychographic microscopy. *Optics Letters*, 38(22), 4845–4848.

- IMX219 Datasheet, Sony Semiconductor Solutions. CMOS image sensor, 8 MP, 1.12 μm pixel.

- SN74HC595 Datasheet, Texas Instruments. 8-bit shift register with output latches.

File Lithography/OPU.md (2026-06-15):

For [Yaeonku BD015](https://www.amazon.com/dp/B0CPP2391F?th=1) OPU

| Pin(s) | Sub-System / Component | Measured Resistance | Status & Functional Notes |
|---|---|---|---|
| 1 | 405nm Laser Diode | N/A | Verified. Laser Cathode / Positive drive pin. Caution: Limit current to <80mA during tests. |
| 2, 3, 29 | Common Ground (GND) | N/A | Verified. Laser Common / System return path. |
| 16, 17, 18, 19 | Photodiode IC (PDIC) | 250Ω – 500Ω | Identified. Transimpedance amplifier outputs for the A, B, C, D astigmatic quadrants. Need to identify quadrant to pin. |
| 31, 32 | Voice Coil Motor (VCM A) | 4Ω | Identified. Low-impedance actuator. Action: Requires 45mA kinematic matrix test to determine if Focus, Tracking, or Tilt. |
| 33, 34 | Voice Coil Motor (VCM B) | 4Ω | Identified. Low-impedance actuator. Action: Requires 45mA kinematic matrix test to determine if Focus, Tracking, or Tilt. |
| 35, 36, 37, 38 | SA / Auxiliary Coil | 4Ω – 60Ω | Identified. Higher impedance indicates a secondary actuator, likely for Spherical Aberration (SA) correction or a micro-tilt element. |

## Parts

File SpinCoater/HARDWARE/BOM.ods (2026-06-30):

PART NUMBER | PART NAME | DESCRIPTION | QUANTITY | UNITS | PART URL | UNIT COST | AMOUNT
ESP32-DevKitC-32E | ESP32 |  | 1 | 1 |  | 11 | 11
BLHeli_32bit AM32 ESC | ESC |  | 1 | 1 |  | 19.99 | 19.99
ILI9341 | 2.4” TFT DISPLAY |  | 1 | 1 |  | 14.99 | 14.99
TMC2209 | Stepper Motor Driver |  | 1 | 6 |  | 5 | 29.99
28BYJ-48 + ULN2003 | Stepper Motor + Driver |  | 1 | 5 |  | 3 | 14.99
A2212 | 930KV Brushless Motor |  | 1 | 1 |  | 12.99 | 12.99
DC 12V to DC 5V 5A | Buck Converter |  | 1 | 2 |  | 7 | 14.99
NEMA 17 Motor 2A | Stepper Motor |  | 1 | 1 |  | 14.99 | 14.99
Misc | 3D Filament, Wires, Hardware |  |  |  |  |  | 50
 |  |  |  |  |  |  | 183.93

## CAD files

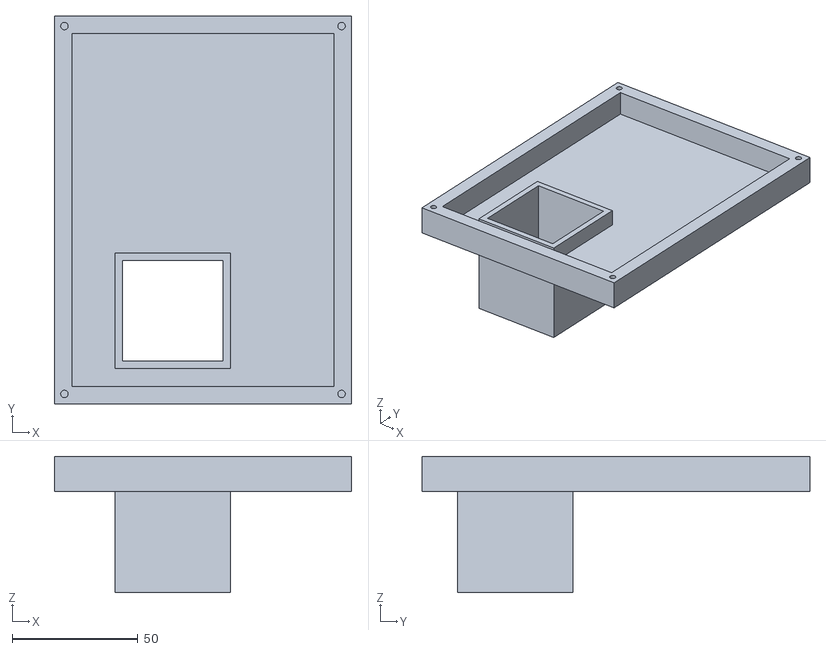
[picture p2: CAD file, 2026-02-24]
Metrology/FPM/Hardware/LED Array Mount.stl
118.0 x 154.0 x 54.0

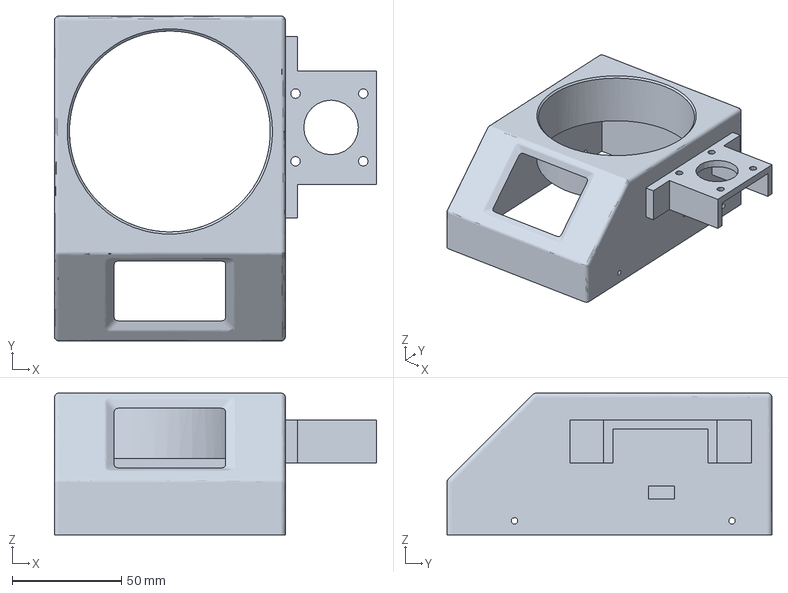
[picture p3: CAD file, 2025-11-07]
SpinCoater/HARDWARE/3D Files/Spinner_Case.3mf
147.6 x 148.9 x 65.0 mm

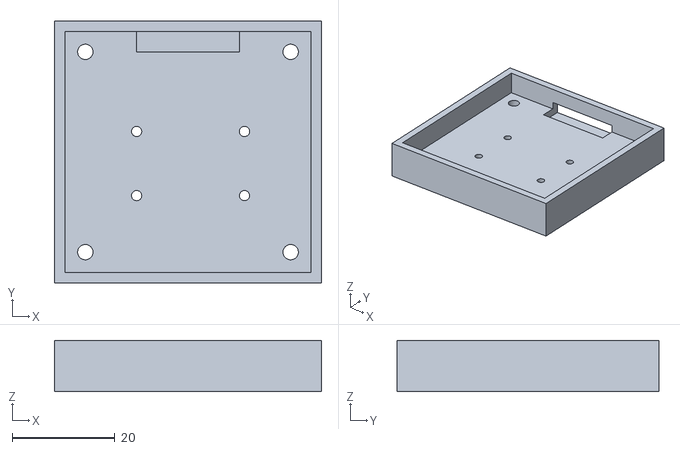
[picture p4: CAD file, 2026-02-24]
Metrology/FPM/Hardware/CameraModule Backing.stl
52.0 x 51.0 x 10.0

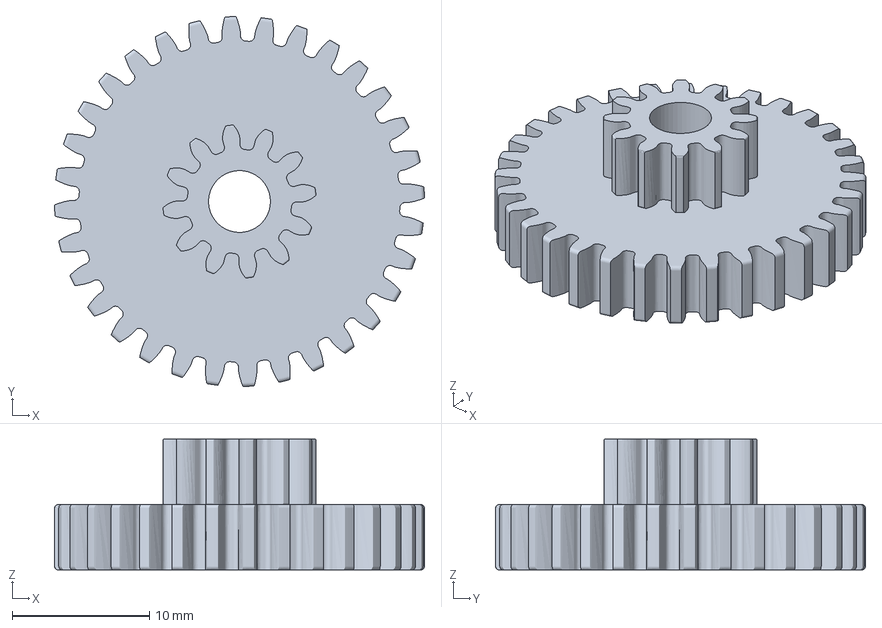
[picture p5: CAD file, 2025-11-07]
SpinCoater/HARDWARE/3D Files/Dispensor_Transm1.3mf
26.9 x 26.9 x 9.52 mm

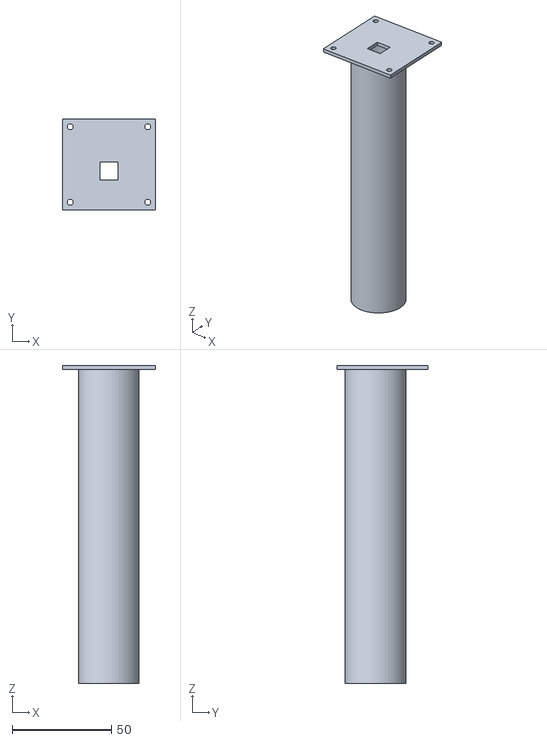
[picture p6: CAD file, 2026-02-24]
Metrology/FPM/Hardware/CamModule.stl
47.0 x 46.0 x 160.0

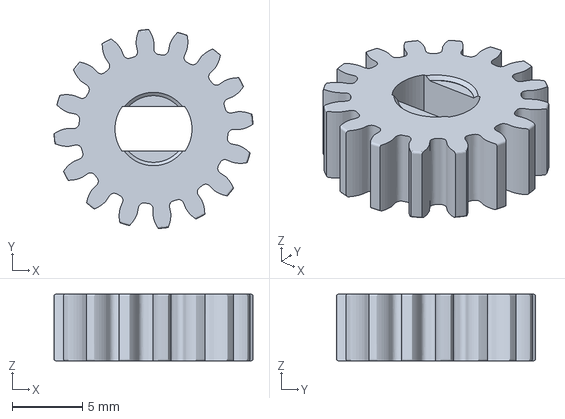
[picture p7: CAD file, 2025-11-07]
SpinCoater/HARDWARE/3D Files/Dispensor_Rad3.3mf
14.2 x 14.2 x 4.76 mm

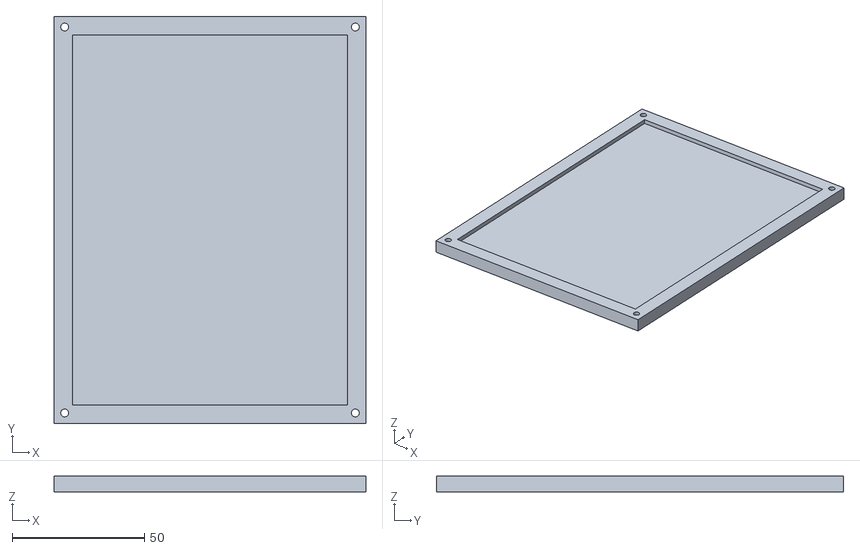
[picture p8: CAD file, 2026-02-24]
Metrology/FPM/Hardware/LED Array Mount Backing.stl
118.0 x 154.0 x 6.00

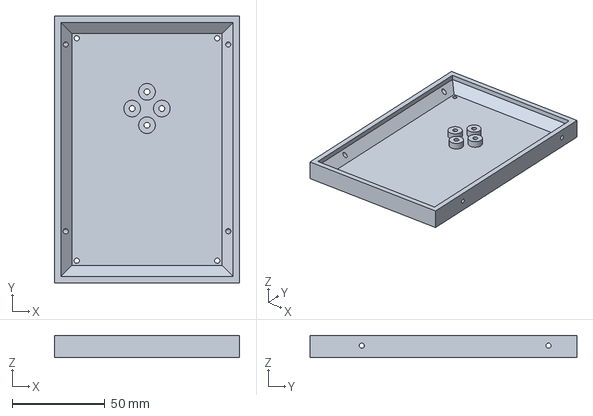
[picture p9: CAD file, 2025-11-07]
SpinCoater/HARDWARE/3D Files/Spinner_Base.3mf
99.8 x 144.0 x 12.0 mm

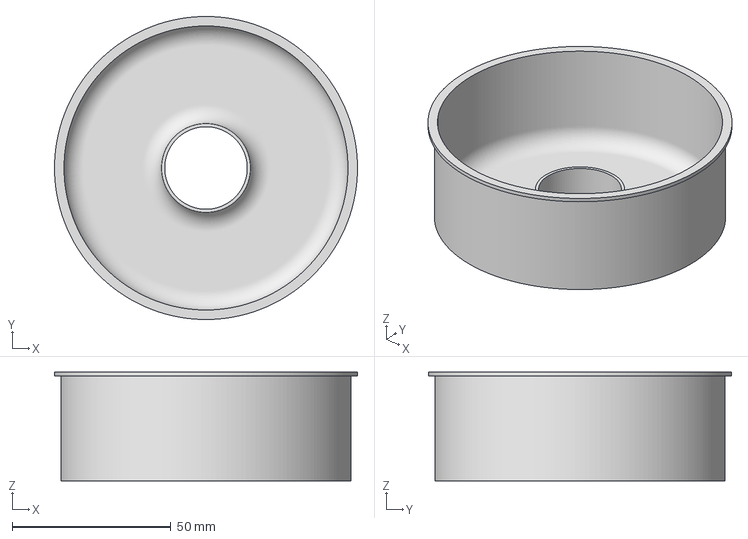
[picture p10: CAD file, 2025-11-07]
SpinCoater/HARDWARE/3D Files/Spinner_Vase.3mf
95.5 x 95.5 x 34.2 mm

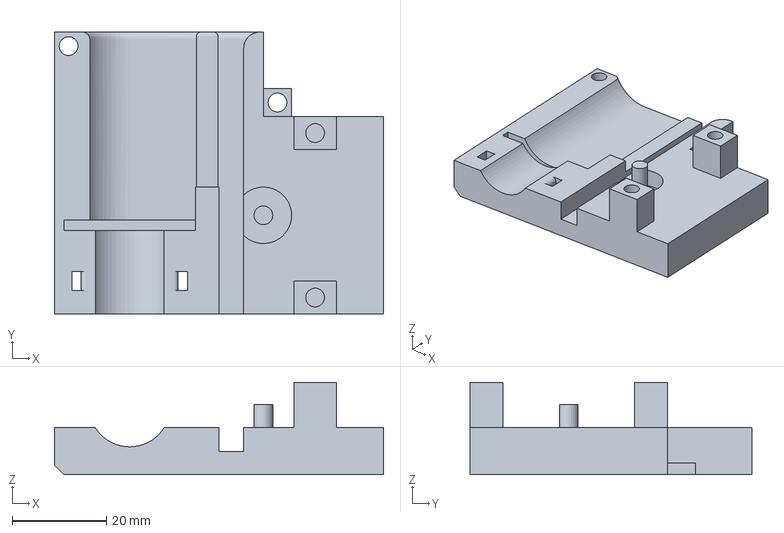
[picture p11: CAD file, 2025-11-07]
SpinCoater/HARDWARE/3D Files/Dispensor_Base.3mf
70.0 x 60.0 x 19.6 mm

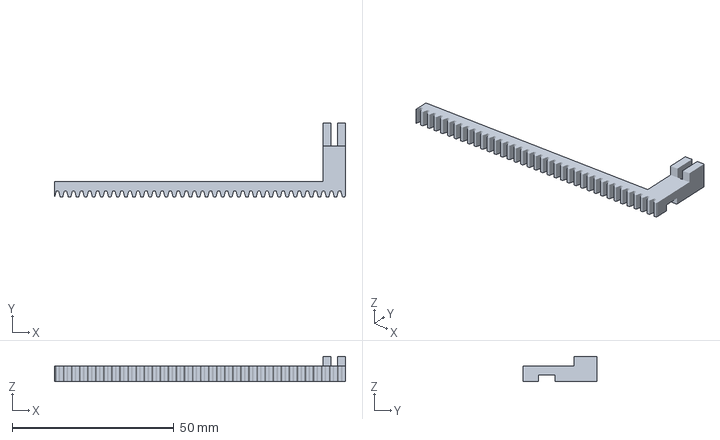
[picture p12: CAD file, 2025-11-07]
SpinCoater/HARDWARE/3D Files/Dispensor_Arm.3mf
90.0 x 22.8 x 7.76 mm

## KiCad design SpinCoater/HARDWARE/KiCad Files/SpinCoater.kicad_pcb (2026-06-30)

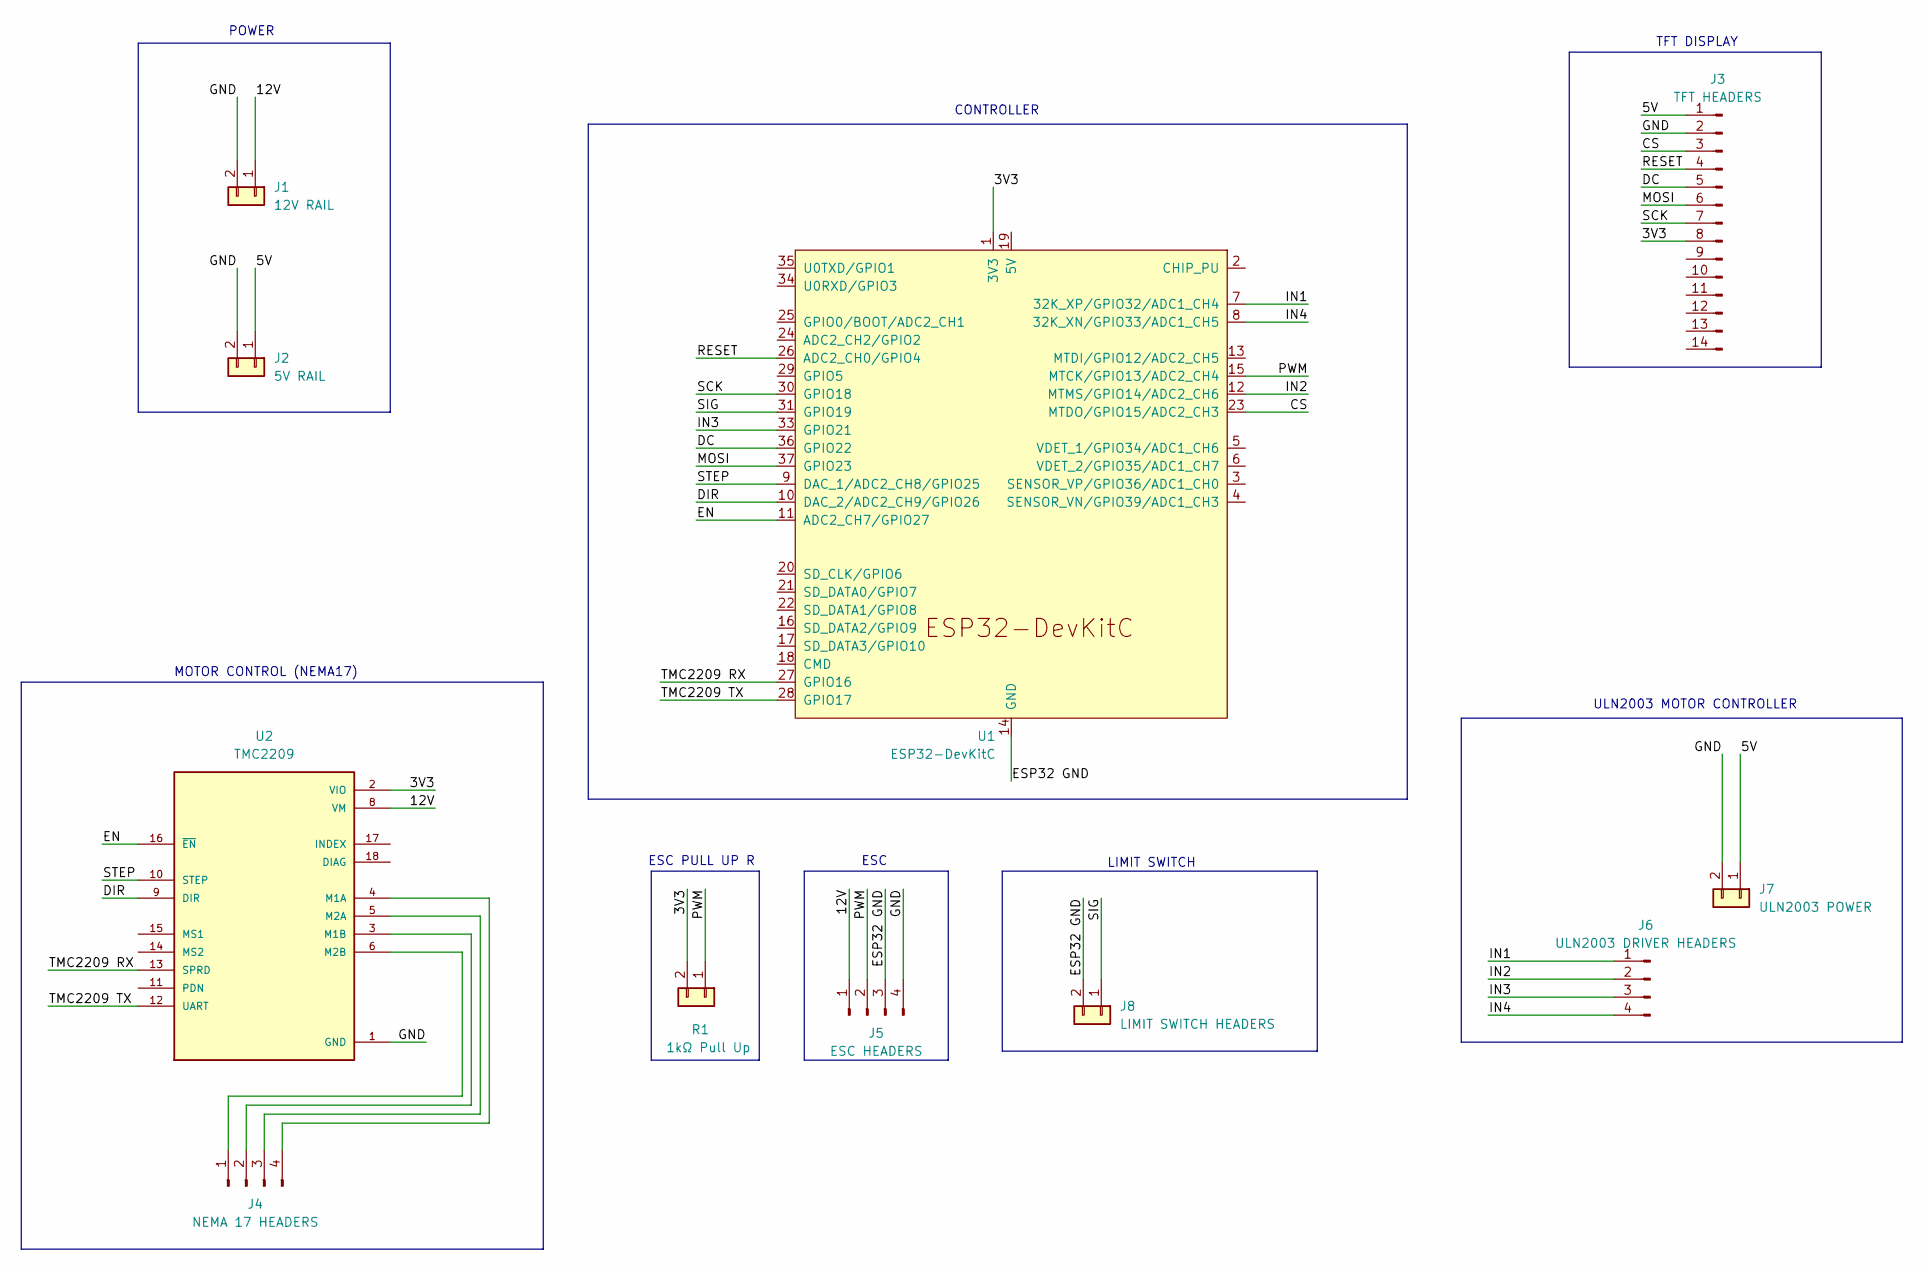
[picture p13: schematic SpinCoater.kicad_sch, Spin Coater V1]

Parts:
J1: 12V RAIL; PinHeader_1x02_P2.54mm_Vertical
J2: 5V RAIL; PinHeader_1x02_P2.54mm_Vertical
J3: TFT HEADERS; PinHeader_1x14_P2.54mm_Vertical
J4: NEMA 17 HEADERS; PinHeader_1x04_P2.54mm_Vertical
J5: ESC HEADERS; PinHeader_1x04_P2.54mm_Vertical
J6: ULN2003 DRIVER HEADERS; PinHeader_1x04_P2.54mm_Vertical
J7: ULN2003 POWER; PinHeader_1x02_P2.54mm_Vertical
J8: LIMIT SWITCH HEADERS; PinHeader_1x02_P2.54mm_Vertical
R1: 1kΩ Pull Up; R_Axial_DIN0207_L6.3mm_D2.5mm_P10.16mm_Horizontal
U1: ESP32-DevKitC
U2: TMC2209; MODULE_TMC2209_SILENTSTEPSTICK; PARTREV 1.20

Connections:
/3V3: J3.8, R1.2, U1.1 (3V3), U2.2 (VIO)
/5V: J2.1, J3.1, J7.1
/12V: J1.1, J5.1, U2.8 (VM)
/CS: J3.3, U1.23 (MTDO/GPIO15/ADC2_CH3)
/DC: J3.5, U1.36 (GPIO22)
/DIR: U1.10 (DAC_2/ADC2_CH9/GPIO26), U2.9 (DIR)
/EN: U1.11 (ADC2_CH7/GPIO27), U2.16 (~EN)
/ESP32 GND: J5.3, J8.2, U1.14 (GND), U1.32 (GND), U1.38 (GND)
/IN1: J6.1, U1.7 (32K_XP/GPIO32/ADC1_CH4)
/IN2: J6.2, U1.12 (MTMS/GPIO14/ADC2_CH6)
/IN3: J6.3, U1.33 (GPIO21)
/IN4: J6.4, U1.8 (32K_XN/GPIO33/ADC1_CH5)
/MOSI: J3.6, U1.37 (GPIO23)
/PWM: J5.2, R1.1, U1.15 (MTCK/GPIO13/ADC2_CH4)
/RESET: J3.4, U1.26 (ADC2_CH0/GPIO4)
/SCK: J3.7, U1.30 (GPIO18)
/SIG: J8.1, U1.31 (GPIO19)
/STEP: U1.9 (DAC_1/ADC2_CH8/GPIO25), U2.10 (STEP)
/TMC2209 RX: U1.27 (GPIO16), U2.13 (SPRD)
/TMC2209 TX: U1.28 (GPIO17), U2.12 (UART)
GND: J1.2, J2.2, J3.2, J5.4, J7.2, U2.1 (GND), U2.7 (GND)
unnamed: J4.1, U2.6 (M2B)
unnamed: J4.2, U2.3 (M1B)
unnamed: J4.3, U2.5 (M2A)
unnamed: J4.4, U2.4 (M1A)

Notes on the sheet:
MOTOR CONTROL (NEMA17)
ESC PULL UP R
ULN2003 MOTOR CONTROLLER
POWER
CONTROLLER
ESC
TFT DISPLAY
LIMIT SWITCH

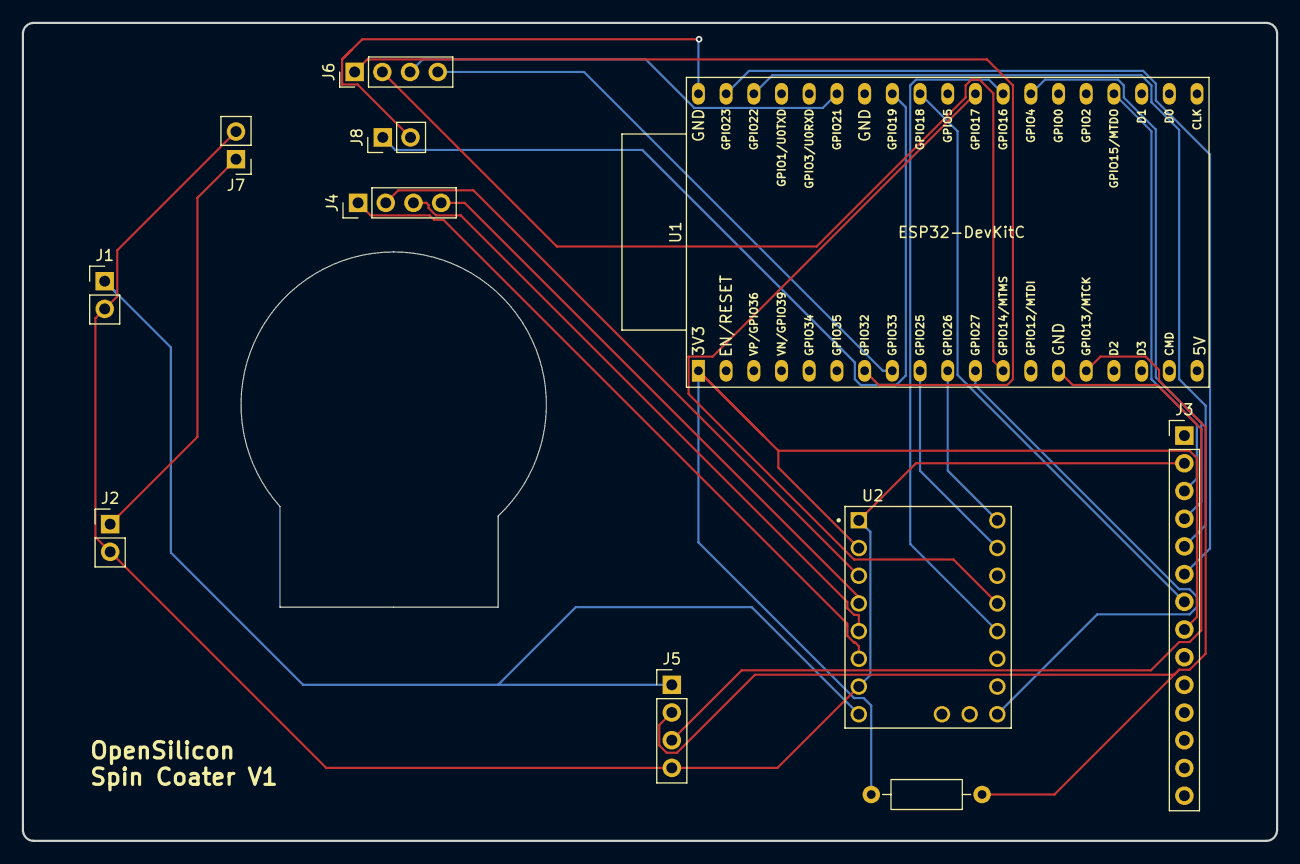
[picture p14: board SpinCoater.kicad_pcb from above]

Board: 2 copper layers, 115.0 x 75.0 mm, 11 parts (0 on the bottom side), 25 nets.

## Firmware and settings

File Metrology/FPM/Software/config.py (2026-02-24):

"""
FPM System Configuration Module

Centralized configuration management using Pydantic for validation.
All physical constants and operational parameters defined here.

OPERATING MODES
---------------
transmission:
    LED array is positioned BELOW the sample. Light passes UP through the
    specimen and into the objective above. Requires a transparent or
    semi-transparent sample (glass slide, quartz, thin photoresist).
    Phase encodes optical path length through the sample:
        height_nm = (phase_rad * wavelength_nm) / (2 * pi * (n - 1))
    where n is the sample refractive index (default 1.5 for glass/resist).

reflection:
    LED array is positioned ABOVE the sample via a 50/50 beam splitter.
    Light reflects off the specimen surface and returns through the
    objective. Suitable for opaque samples (silicon wafers, metal films).
    Phase encodes surface topography via double-pass path length:
        height_nm = (phase_rad * wavelength_nm) / (4 * pi)

Both modes run full FPM reconstruction to achieve synthetic-aperture
resolution beyond the conventional Abbe diffraction limit.

IMPORTANT: Current plastic calibration target exhibits UV-induced fluorescence
at exposures >8-10 seconds. Configuration optimized to stay below threshold.
For longer exposures, use UV-transparent quartz target instead.
"""

from pydantic import Field
from pydantic_settings import BaseSettings, SettingsConfigDict
from pathlib import Path
from typing import Literal

# Valid operating modes. Referenced by client, server, and visualizer.
OperatingMode = Literal["transmission", "reflection"]


class OpticalConfig(BaseSettings):
    """
    Optical system physical parameters.
    
    These values must match the actual hardware configuration.
    Changing these requires recalibration.
    """
    
    wavelength_nm: float = Field(
        default=395.0,
        description="LED center wavelength in nanometers (UV)",
        ge=380.0,
        le=420.0
    )
    
    na_objective: float = Field(
        default=0.25,
        description="Numerical aperture of objective lens",
        gt=0.0,
        lt=1.0
    )
    
    pixel_size_um: float = Field(
        default=1.12,
        description="Camera pixel pitch in micrometers (IMX219 sensor native)",
        gt=0.0
    )
    
    magnification: float = Field(
        default=10.0,
        description="Objective magnification factor",
        gt=0.0
    )
    
    led_pitch_mm: float = Field(
        default=8.0,
        description="LED array grid spacing in millimeters (5x5 grid)",
        gt=0.0
    )
    
    led_height_mm: float = Field(
        default=50.0,
        description="Distance from LED array to sample plane in millimeters",
        gt=0.0
    )

    sample_refractive_index: float = Field(
        default=1.5,
        description=(
            "Sample refractive index — used only in transmission mode "
            "to convert phase to physical thickness. "
            "Typical values: glass/quartz=1.46, photoresist=1.52, water=1.33."
        ),
        gt=1.0,
        lt=3.0
    )
    
    @property
    def wavelength_m(self) -> float:
        """Wavelength in meters."""
        return self.wavelength_nm * 1e-9
    
    @property
    def pixel_size_m(self) -> float:
        """Effective pixel size at sample plane in meters."""
        return (self.pixel_size_um * 1e-6) / self.magnification
    
    @property
    def led_pitch_m(self) -> float:
        """LED pitch in meters."""
        return self.led_pitch_mm * 1e-3
    
    @property
    def led_height_m(self) -> float:
        """LED height in meters."""
        return self.led_height_mm * 1e-3
    
    @property
    def theoretical_resolution_nm(self) -> float:
        """Theoretical Abbe resolution limit in nanometers."""
        return (self.wavelength_nm / (2 * self.na_objective))
    
    @property
    def synthetic_na_estimate(self) -> float:
        """Estimated synthetic NA after FPM reconstruction."""
        import numpy as np
        # Corner LED angle
        corner_dist = np.sqrt(2) * (2 * self.led_pitch_mm / 1000)
        theta_max = np.arctan(corner_dist / (self.led_height_mm / 1000))
        na_illumination = np.sin(theta_max)
        return min(self.na_objective + na_illumination, 0.95)
    
    @property
    def synthetic_resolution_nm(self) -> float:
        """Theoretical resolution after FPM reconstruction in nanometers."""
        return (self.wavelength_nm / (2 * self.synthetic_na_estimate))


class ReconstructionConfig(BaseSettings):
    """
    Fourier ptychography reconstruction algorithm parameters.
    """
    
    upsample_factor: int = Field(
        default=4,
        description="Spectral resolution enhancement factor (2-8x)",
        ge=2,
        le=8
    )
    
    max_iterations: int = Field(
        default=15,
        description="Maximum Gerchberg-Saxton iterations (increased for noisy data)",
        ge=1,
        le=100
    )
    
    convergence_threshold: float = Field(
        default=1e-4,
        description="Relative change threshold for early stopping",
        gt=0.0
    )
    
    regularization_weight: float = Field(
        default=0.01,
        description="Tikhonov regularization parameter (reduces noise amplification)",
        ge=0.0,
        le=1.0
    )


class AcquisitionConfig(BaseSettings):
    """
    Image acquisition hardware parameters.
    
    FLUORESCENCE WARNING:
    Current plastic calibration target exhibits UV-induced fluorescence
    at exposures >8-10 seconds. These settings stay below threshold.
    
    For better signal quality:
    1. Use UV-transparent quartz target (allows 60-120s exposures)
    2. Switch to blue LEDs 470nm (no fluorescence, 10x faster)
    3. Use maximum gain to compensate for short exposures
    """
    
    serial_port: str = Field(
        default="/dev/ttyUSB0",
        description="ESP32 serial port device path"
    )
    
    baud_rate: int = Field(
        default=115200,
        description="Serial communication baud rate",
        gt=0
    )
    
    camera_width: int = Field(
        default=2048,
        description="Camera capture width in pixels",
        ge=512,
        le=4096
    )
    
    camera_height: int = Field(
        default=2048,
        description="Camera capture height in pixels",
        ge=512,
        le=4096
    )
    
    # EXPOSURE TIMES: Optimized for plastic target (below fluorescence threshold)
    bf_exposure_us: int = Field(
        default=9600000,
        description="Bright-field exposure in microseconds (7s - below fluorescence threshold)",
        gt=0
    )
    
    df_exposure_us: int = Field(
        default=9600000,
        description="Dark-field exposure in microseconds (7s - same as BF to avoid fluorescence)",
        gt=0
    )
    
    analog_gain: float = Field(
        default=16.0,
        description="Camera analog gain (16.0 = maximum, needed for short exposures)",
        ge=1.0,
        le=16.0
    )
    
    capture_timeout_s: int = Field(
        default=60,
        description="Maximum time to wait for single image capture (seconds)",
        gt=0
    )
    
    # NOTE: Removed exposure validator to allow longer exposures with quartz targets
    # If using quartz target, you can safely use:
    #   bf_exposure_us = 60000000  (60 seconds)
    #   df_exposure_us = 120000000 (120 seconds)


class ServerConfig(BaseSettings):
    """
    FastAPI server and storage configuration.
    """
    
    model_config = SettingsConfigDict(env_file=".env", env_file_encoding="utf-8")
    
    data_root: Path = Field(
        default=Path("./data"),
        description="Root directory for session data storage"
    )
    
    host: str = Field(
        default="0.0.0.0",
        description="Server bind address (0.0.0.0 = all interfaces)"
    )
    
    port: int = Field(
        default=8000,
        description="Server port",
        gt=0,
        lt=65536
    )
    
    log_level: Literal["DEBUG", "INFO", "WARNING", "ERROR"] = Field(
        default="INFO",
        description="Logging verbosity level"
    )
    
    max_upload_size_mb: int = Field(
        default=500,
        description="Maximum total upload size per session in megabytes",
        gt=0
    )
    
    worker_threads: int = Field(
        default=2,
        description="Number of background reconstruction worker threads",
        ge=1,
        le=8
    )
    
    def __init__(self, **kwargs):
        super().__init__(**kwargs)
        self.data_root.mkdir(parents=True, exist_ok=True)


class SystemConfig(BaseSettings):
    """
    Top-level system configuration aggregating all subsystems.

    Environment variables can override defaults using FPM_ prefix:
    - FPM_MODE=transmission
    - FPM_ACQUISITION__BF_EXPOSURE_US=60000000
    - FPM_ACQUISITION__ANALOG_GAIN=8.0
    - FPM_SERVER__DATA_ROOT=/mnt/data
    - FPM_OPTICAL__SAMPLE_REFRACTIVE_INDEX=1.46

    OPERATING MODES:

    transmission  LED below sample. Phase → optical path length through sample.
                  Height = phase * λ / (2π(n-1)).  Use for glass, resist, quartz.

    reflection    LED above sample via beam splitter. Phase → surface height.
                  Height = phase * λ / (4π).  Use for silicon, metal, opaque films.

    EXPOSURE PROFILES:

    Profile 1: Plastic Target (CURRENT)
    - bf_exposure_us = 7000000 (7s)
    - df_exposure_us = 7000000 (7s)
    - analog_gain = 16.0
    - Signal: ~20-40 mean (8-16% range) - marginal
    - Pros: Works with existing target
    - Cons: Weak signal, high noise

    Profile 2: Quartz Target (RECOMMENDED)
    - bf_exposure_us = 60000000 (60s)
    - df_exposure_us = 120000000 (120s)
    - analog_gain = 8.0
    - Signal: ~80-150 mean (30-60% range) - good
    - Pros: Strong signal, low noise
    - Cons: Requires quartz slide ($30-80)

    Profile 3: Blue LEDs (BEST LONG-TERM)
    - wavelength_nm = 470.0
    - bf_exposure_us = 1000000 (1s)
    - df_exposure_us = 3000000 (3s)
    - analog_gain = 4.0
    - Signal: ~100-200 mean (40-80% range) - excellent
    - Pros: Fast, no fluorescence, visible
    - Cons: Requires LED replacement ($10-50)
    """

    mode: OperatingMode = Field(
        default="reflection",
        description=(
            "Operating geometry. 'reflection' = LED above sample via beam "
            "splitter (opaque samples). 'transmission' = LED below sample "
            "(transparent samples). Both modes run full FPM reconstruction."
        )
    )

    optical: OpticalConfig = Field(default_factory=OpticalConfig)
    reconstruction: ReconstructionConfig = Field(default_factory=ReconstructionConfig)
    acquisition: AcquisitionConfig = Field(default_factory=AcquisitionConfig)
    server: ServerConfig = Field(default_factory=ServerConfig)

    model_config = SettingsConfigDict(env_file=".env", env_prefix="FPM_")

    def print_summary(self):
        """Print configuration summary including active mode."""
        mode_detail = {
            "reflection": (
                "LED above sample via beam splitter | "
                "Phase → surface height = φλ/(4π)"
            ),
            "transmission": (
                f"LED below sample | "
                f"Phase → thickness = φλ/(2π(n-1)), n={self.optical.sample_refractive_index}"
            ),
        }[self.mode]

        print("=" * 70)
        print("FPM SYSTEM CONFIGURATION SUMMARY")
        print("=" * 70)
        print(f"Operating mode:       {self.mode.upper()}")
        print(f"  {mode_detail}")
        print(f"\nWavelength:           {self.optical.wavelength_nm} nm")
        print(f"Objective NA:         {self.optical.na_objective}")
        print(f"Synthetic NA (est):   {self.optical.synthetic_na_estimate:.3f}")
        print(f"Theoretical res:      {self.optical.theoretical_resolution_nm:.1f} nm")
        print(f"Synthetic res (est):  {self.optical.synthetic_resolution_nm:.1f} nm")
        if self.mode == "transmission":
            print(
                f"Sample refractive idx: {self.optical.sample_refractive_index} "
                f"(set FPM_OPTICAL__SAMPLE_REFRACTIVE_INDEX to override)"
            )
        print(f"\nBright-field exp:     {self.acquisition.bf_exposure_us / 1e6:.1f}s")
        print(f"Dark-field exp:       {self.acquisition.df_exposure_us / 1e6:.1f}s")
        print(f"Analog gain:          {self.acquisition.analog_gain}x")
        print(f"\nTotal acq time (est): {self._estimate_acquisition_time():.1f} minutes")
        print(f"Data root:            {self.server.data_root}")
        print("=" * 70)
    
    def _estimate_acquisition_time(self) -> float:
        """Estimate total acquisition time in minutes."""
        # 9 bright-field LEDs, 16 dark-field LEDs
        bf_time_s = 9 * (self.acquisition.bf_exposure_us / 1e6)
        df_time_s = 16 * (self.acquisition.df_exposure_us / 1e6)
        overhead_s = 25 * 2  # 2 seconds overhead per LED
        total_s = bf_time_s + df_time_s + overhead_s
        return total_s / 60


# Global singleton instance
config = SystemConfig()


# Development/debugging helper
if __name__ == "__main__":
    config.print_summary()

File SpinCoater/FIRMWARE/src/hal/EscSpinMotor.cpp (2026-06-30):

#include "hal/implementations/EscSpinMotor.h"
#include "common/configs.h"
#include "common/pin_mapping.h"
#include <Arduino.h>

namespace HAL {
    static const int32_t MIN_OPERATING_RPM = 200;

    // Throttle units for DSHOT::set(int): 0..2000. The library adds the +48
    // DShot offset internally, so 0 here = lowest spinning throttle (DShot 48).
    static const int32_t THROTTLE_MAX = 1999;
    static const int32_t THROTTLE_MIN_SPIN = 100;   // floor once the motor is turning
    static const int32_t STARTUP_THROTTLE = 200;    // open-loop kick to break stiction

    // Closed-loop speed control. Under the near-constant load of a spin coater
    // the ESC maps throttle (0..THROTTLE_MAX) onto speed roughly linearly, so a
    // linear feedforward seeds the loop and a PI controller trims the nonlinear
    // remainder and holds the setpoint. Tune these against your motor/load.
    static const float SPEED_KP = 0.10f;              // throttle units per RPM error
    static const float SPEED_KI = 0.30f;              // throttle units per RPM error per second
    static const float THROTTLE_FF_PER_RPM = 0.12f;   // feedforward seed (throttle per target RPM)

    EscSpinMotor::EscSpinMotor(gpio_num_t pin, uint32_t dshotSpeedKbps, uint8_t motorPoles)
        : pin_(pin),
          motorPoles_(motorPoles)
    {
        (void)dshotSpeedKbps;  // speed/protocol is fixed at DSHOT300_BIDIR (see begin())
    }

    bool EscSpinMotor::enqueueCommand(EscCommandType type, int32_t rpm) {
        if (cmdQueue_ == nullptr) {
            return false;
        }
        EscCommand cmd{type, rpm};
        return xQueueSend(cmdQueue_, &cmd, pdMS_TO_TICKS(10)) == pdTRUE;
    }

    void EscSpinMotor::begin() {
        pinMode(STATUS_LED_PIN, OUTPUT);
        digitalWrite(STATUS_LED_PIN, LOW);

        // Bidirectional DShot300 on a single wire: throttle out, GCR eRPM in.
        // DShot1200 bidir is unreliable on ESP32; 300 is the sweet spot.
        if (!dshot_.begin(static_cast<int>(pin_), DSHOT::DSHOT300_BIDIR)) {
            Serial.println("ERROR: DShot begin failed (no free RMT channels?)");
        }

        // Spin-direction commands must be repeated several times to take effect.
        for (int i = 0; i < 10; i++) {
            dshot_.cmd(DSHOT::DSHOT_CMD_SPIN_DIRECTION_NORMAL);
            delay(1);
        }

        DSHOT::arm();  // ~1.5s: line low, motor-stop, zero throttle
        Serial.println("ESC armed");

        cmdQueue_ = xQueueCreate(8, sizeof(EscCommand));
        if (cmdQueue_ == nullptr) {
            Serial.println("ERROR: ESC command queue creation failed");
            return;
        }

        BaseType_t created = xTaskCreatePinnedToCore(
            taskEntry,
            "EscSpin",
            4096,
            this,
            4,
            &taskHandle_,
            0
        );
        if (created != pdPASS) {
            Serial.println("ERROR: EscSpin task creation failed");
        }
    }

    void EscSpinMotor::taskEntry(void* param) {
        auto* self = static_cast<EscSpinMotor*>(param);
        TickType_t lastWake = xTaskGetTickCount();
        const TickType_t period = pdMS_TO_TICKS(ESC_UPDATE_INTERVAL_MS);

        for (;;) {
            self->updateLoop();
            vTaskDelayUntil(&lastWake, period);
        }
    }

    void EscSpinMotor::update() {}

    void EscSpinMotor::processCommands() {
        EscCommand cmd;
        while (xQueueReceive(cmdQueue_, &cmd, 0) == pdTRUE) {
            if (cmd.type == EscCommandType::SetTarget) {
                int32_t rpm = cmd.rpm;
                if (rpm > MAX_RPM) rpm = MAX_RPM;
                if (rpm < 0) rpm = 0;
                targetRPM_ = rpm;
                reportedTargetRPM_.store(rpm, std::memory_order_relaxed);
            } else {
                targetRPM_ = 0;
                reportedTargetRPM_.store(0, std::memory_order_relaxed);
                integrator_ = 0.0f;
            }
        }
    }

    void EscSpinMotor::readTelemetry() {
        // erpm_us is the eRPM period in microseconds (0 = stopped / unavailable).
        // Updated by the library's RX ISR after each bidirectional frame.
        const uint16_t period_us = dshot_.erpm_us;
        const uint32_t polePairs = motorPoles_ ? (motorPoles_ / 2) : 1;

        int32_t mechRPM = 0;
        int32_t eRPM = 0;
        if (period_us > 0) {
            eRPM = static_cast<int32_t>(60000000UL / period_us);  // electrical RPM
            mechRPM = eRPM / static_cast<int32_t>(polePairs);
        }

        // Light EMA (alpha 0.4) smooths the jittery per-frame eRPM for both the
        // control loop and telemetry; snap straight to 0 when the motor stops.
        if (mechRPM == 0) {
            actualRPM_.store(0, std::memory_order_relaxed);
        } else {
            const int32_t prev = actualRPM_.load(std::memory_order_relaxed);
            actualRPM_.store(prev + ((mechRPM - prev) * 2) / 5, std::memory_order_relaxed);
        }
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

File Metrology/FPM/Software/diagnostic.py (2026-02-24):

"""
FPM Post-Hoc Diagnostic Tool

Reads an existing 25-image session from disk and produces specific,
quantitative adjustment instructions — no hardware required.

Distinct from the other tools:

    val.py          PASS / WARN / FAIL status per LED.
                    Tells you *what* is wrong.

    calibration.py  Live-hardware checks + auto-tune.
                    Requires ESP32 + camera connected.

    diagnose.py     (THIS FILE)
                    Reads any existing session and tells you *exactly*
                    what to change and by how much:
                        • "led_height_mm is actually 43.2 mm — config says 50.0"
                        • "shift LED array 4.2 mm right, 1.1 mm towards camera"
                        • "set bf_exposure_us = 28_800_000 (3.0× current)"
                        • "set df_exposure_us = 43_200_000 (4.5× current)"
                        • "focus OK — Laplacian score 24.3 (threshold 5.0)"

Three diagnostic axes
─────────────────────
1. GEOMETRY  — fit led_height_mm and LED-array lateral offset from all 25
               measured centroids using nonlinear least-squares.
               Inputs:  measured centroids (from bright-spot detection)
               Outputs: inferred height, inferred x/y array offset (mm),
                        residuals per LED, dominant error type.

2. EXPOSURE  — per-LED mean/clip statistics; separate BF and DF groups;
               recommend new bf_exposure_us and df_exposure_us.
               Flags fluorescence risk (plastic + UV + long exposure).

3. FOCUS     — Laplacian variance per LED on the central ROI.
               Identifies best-focused LED, worst, and spatial gradient
               (detects sample tilt or non-flat mounting).

Usage
─────
    python diagnose.py data/fpm_1771832995
    python diagnose.py data/fpm_1771832995 --no-plot
    python diagnose.py data/fpm_1771832995 --json-only

Outputs (written to session directory)
───────────────────────────────────────
    diagnosis_report.json   full structured data
    diagnosis_summary.txt   human-readable plain-text report
    diagnosis_plot.png      3×2 annotated visualisation (optional)
"""

from __future__ import annotations

import argparse
import json
import logging
import sys
from dataclasses import dataclass, asdict, field
from pathlib import Path
from typing import Dict, List, Optional, Tuple

import cv2
import numpy as np

# scipy for nonlinear least-squares geometry fit
try:
    from scipy.optimize import minimize
    _SCIPY = True
except ImportError:
    _SCIPY = False

from imgload import load_uv_image
from config import config as _global_config, SystemConfig

logger = logging.getLogger("FPMDiagnose")

# ---------------------------------------------------------------------------
# Constants
# ---------------------------------------------------------------------------

# BF LED indices (1-based, row-major 5×5 grid, inner 3×3)
BF_LEDS = {7, 8, 9, 12, 13, 14, 17, 18, 19}

# Centre LED (1-based)
CENTRE_LED = 13

# Exposure target: centre of the acceptable window
_EXPOSURE_TARGET_PCT = 47.5          # % of 8-bit full scale
_EXPOSURE_FSR        = 255.0
_FLUORESCENCE_LIMIT_US = 7_000_000  # 7 s — plastic UV fluorescence onset

# Focus thresholds (Laplacian variance on central ROI)
_FOCUS_PASS = 5.0
_FOCUS_WARN = 2.0

# Geometry fit bounds
_HEIGHT_MIN_MM = 10.0
_HEIGHT_MAX_MM = 200.0


# ---------------------------------------------------------------------------
# Per-LED measurement
# ---------------------------------------------------------------------------

@dataclass
class LEDMeasurement:
    led_number: int           # 1–25
    is_bf: bool
    centroid_x: Optional[float]   # None if detection failed
    centroid_y: Optional[float]
    peak_intensity: Optional[float]
    mean_intensity: float
    laplacian_score: float
    centroid_ok: bool
    snr: float                # peak / (mean + eps)


def _bright_centroid(img: np.ndarray) -> Tuple[float, float, float]:
    """
    Intensity-weighted centroid of the top-5% brightest pixels.
    Returns (cx, cy, peak).  Raises ValueError if no signal.
    """
    threshold = np.percentile(img, 95)
    mask = img > threshold
    if not np.any(mask):
        raise ValueError("No bright region above 95th percentile")
    masked = img * mask.astype(np.float32)
    total  = masked.sum()
    if total < 1e-6:
        raise ValueError("Bright region has negligible intensity")
    rows = np.arange(img.shape[0]).reshape(-1, 1)
    cols = np.arange(img.shape[1]).reshape(1, -1)
    cy = float((masked * rows).sum() / total)
    cx = float((masked * cols).sum() / total)
    peak = float(img[mask].max())
    return cx, cy, peak


def _laplacian_score(img: np.ndarray) -> float:
    """Normalised Laplacian variance on the central 50% ROI."""
    h, w = img.shape
    roi = img[h // 4: 3 * h // 4, w // 4: 3 * w // 4].astype(np.float32)
    lap = cv2.Laplacian(roi, cv2.CV_32F)
    return float(lap.var())


def measure_session(
    session_path: Path,
) -> Tuple[List[LEDMeasurement], Tuple[int, int]]:
    """
    Load all 25 LED images and compute per-LED measurements.

    Returns:
        (measurements, image_shape) where image_shape is (height, width).
    """
    measurements: List[LEDMeasurement] = []
    image_shape: Optional[Tuple[int, int]] = None

    for led_number in range(1, 26):
        path = session_path / f"led_{led_number:02d}.png"
        if not path.exists():
            logger.warning(f"Missing: {path.name}")
            continue

        img = load_uv_image(path)
        if img is None:
            logger.warning(f"Could not read: {path.name}")
            continue
        img = img.astype(np.float32)

        if image_shape is None:
            image_shape = img.shape

        mean_val = float(img.mean())
        lap      = _laplacian_score(img)

        try:
            cx, cy, peak = _bright_centroid(img)
            centroid_ok  = True
        except ValueError:
            cx = cy = peak = None
            centroid_ok    = False

        snr = float(peak / (mean_val + 1e-6)) if peak is not None else 0.0

        measurements.append(LEDMeasurement(
            led_number     = led_number,
            is_bf          = led_number in BF_LEDS,
            centroid_x     = cx,
            centroid_y     = cy,
            peak_intensity = peak,
            mean_intensity = mean_val,
            laplacian_score= lap,
            centroid_ok    = centroid_ok,
            snr            = snr,
        ))

    if image_shape is None:
        raise RuntimeError("No readable images found in session")

    return measurements, image_shape


# ---------------------------------------------------------------------------
# AXIS 1 — Geometry diagnostic
# ---------------------------------------------------------------------------
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

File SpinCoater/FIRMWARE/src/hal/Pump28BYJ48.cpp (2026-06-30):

#include "hal/implementations/Pump28BYJ48.h"

namespace HAL {
    Pump28BYJ48::Pump28BYJ48(uint8_t in1, uint8_t in2, uint8_t in3, uint8_t in4, float stepsPerML)
        : stepper_(AccelStepper::HALF4WIRE, in1, in2, in3, in4),
          stepsPerML_(stepsPerML),
          totalDispensed_(0.0f),
          busy_(false)
    {}

    void Pump28BYJ48::begin() {
        stepper_.setMaxSpeed(1000);
        stepper_.setAcceleration(200);
        stepper_.setCurrentPosition(0);
    }

    void Pump28BYJ48::dispense(float volume_ml) {
        long steps = volume_ml * stepsPerML_;
        stepper_.move(steps);
        busy_ = true;
    }

    void Pump28BYJ48::aspirate(float volume_ml) {
        long steps = -volume_ml * stepsPerML_;
        stepper_.move(steps);
        busy_ = true;
    }

    void Pump28BYJ48::stop() {
        stepper_.stop();
        busy_ = false;
    }

    bool Pump28BYJ48::isBusy() const {
        return stepper_.distanceToGo() != 0;
    }

    float Pump28BYJ48::getTotalDispensed_ml() const {
        return totalDispensed_;
    }

    void Pump28BYJ48::update() {
        if (busy_) {
            stepper_.run();
            if (!stepper_.isRunning()) {
                long moved = stepper_.currentPosition();
                totalDispensed_ += moved / stepsPerML_;
                stepper_.setCurrentPosition(0);
                busy_ = false;
            }
        }
    }
}

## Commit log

2025-11-07 First working stage of SpinCoater Firmware
    [Dispensor_Arm.3mf, Dispensor_Base.3mf, Dispensor_Rad3.3mf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]
2025-11-09 Initial implementation of TFT display and homing sequence
2026-06-15 Create OPU.md
    Current pinout mappings for OPU
2026-06-30 Spin Coater V1 FIRMWARE FINAL
    - Updated and refactored firmware
    - Designed custom PCB and update KiCad files
    - (TODO) Update and finalize 3D printed housing and files
    - Included BOM
    [BOM.ods, Dispensor_Arm.3mf, Dispensor_Base.3mf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]

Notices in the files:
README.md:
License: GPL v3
